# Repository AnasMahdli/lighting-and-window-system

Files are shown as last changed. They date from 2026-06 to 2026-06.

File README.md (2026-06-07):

# Setup Guide

---

## ⚙️ Hardware Setup

Connect a **12V 2A adapter** to power the complete system.

- The motor drivers (**L298N**) are connected directly to the **12V supply** to prevent brownouts during heavy loads.
- Use a **buck converter** to step down the voltage to **5V** to safely power the ESP32 and the sensor suite (DHT22, LDRs, PIR, MQ5).

---

## 💻 Software Setup

### Required Libraries

Install the following libraries in your **Arduino IDE**:

| Library | Author |
|---|---|
| `ArduinoJson` | Benoit Blanchon |
| `WebSockets` | Markus Sattler |
| `DHT sensor library` | Adafruit |
| `UbidotsEsp32Mqtt` | Ubidots |

### Cloud Configuration

1. Add your Wi-Fi **`SSID`** and **`Password`** to the ESP32 code.
2. Replace the GCP WebApp URL with your specific **Google Apps Script deployment URL**.
   > **Note:** If you update your Apps Script code, you must publish a **"New Deployment"** for the changes to take effect.
3. Ensure your **BigQuery Studio** table schema exactly matches the variable names in your payload (e.g., set `gas_level` to `FLOAT`).

---

## ☁️ Ubidots Setup (MQTT)

To utilize the cloud dashboard:

1. Copy your **Ubidots Token** and **Device Name** into the ESP32 code.
2. In your Ubidots Dashboard, create a new device and add the following raw variables:
   - `system-mode`
   - `fan-control`
   - `curtain-control`
   - `window-control`
3. Link these variables to **toggle switches** on your dashboard. These will publish commands to the ESP32 via the MQTT `/lv` (Last Value) topics.

---

## 🌐 WebSocket Setup (3D Digital Twin)

To run the local First-Person 3D Control Room:

### Prerequisites

1. Download and install the latest **LTS version of Node.js** from [nodejs.org](https://nodejs.org).
2. Download **Ngrok**, extract it, and authenticate your token via the command terminal.

### Installation

Open a command prompt in your project folder and install the required dependencies:

```bash
npm install ws
```

### Running the Servers

You will need **three separate terminals** open in your project folder.

**Terminal 1 — Start the WebSocket Broker:**

```bash
node server.js
```

**Terminal 2 — Host the 3D Files:**

> Note the port used — typically `8081` if `8080` is already taken by the broker.

```bash
npx http-server -p 8081
```

**Terminal 3 — Expose the WebSocket Broker via Ngrok:**

```bash
ngrok http 8080
```

### Connecting the Digital Twin

1. Ngrok will generate a **forwarding URL** in Terminal 3.
2. In your `3d-dashboard.html` file, update the WebSocket connection using the `wss://` prefix:
   ```
   wss://new-random-words.ngrok-free.dev
   ```
3. In your **ESP32 code**, paste the exact same URL but **remove the prefix**:
   ```
   new-random-words.ngrok-free.dev
   ```
4. Open your browser and navigate to:
   ```
   http://127.0.0.1:8081/3d-dashboard.html
   ```

The 3D environment should now render and sync with your physical hardware in real-time. 🚀

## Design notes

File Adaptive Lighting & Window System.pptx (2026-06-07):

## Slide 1

Adaptive Lighting &
Window System

Autonomous IoT Environmental Control & 3D Digital Twin Integration

Anas Hatem Mahdali | 239045

The British University in Egypt | Industrial Internet of Things | 25MTRN04H

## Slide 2

The Cost of Energy Waste

12.05

kWh Wasted Per Home/Year

Inefficient Resource Management

Average households lose significant energy due to forgotten lighting and ventilation. This project leverages the ESP32 to bridge the gap between occupant behavior and environmental efficiency.

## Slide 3

System Objectives

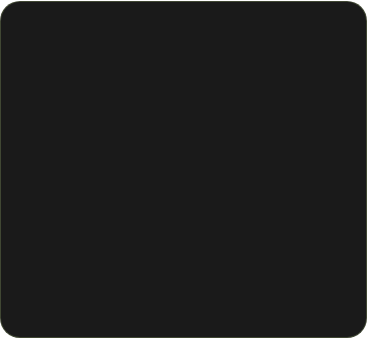
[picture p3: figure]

Autonomy

Intelligent control of lighting and windows based on real-time sensory perception.

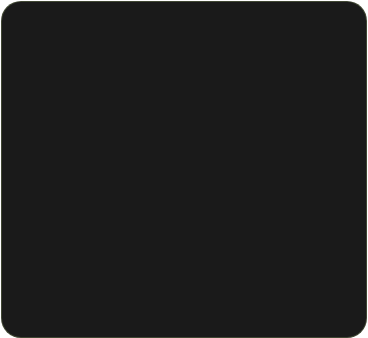
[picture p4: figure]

Safety

Prioritizing human life through advanced gas leak detection and automated ventilation.

Transparency

Real-time telemetry mirrored through 2D cloud dashboards and 3D digital twins.

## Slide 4

Perception Layer: Sensors

DHT22: High-precision temperature and humidity tracking.

LDR 1 & 2: Mapping interior vs. exterior ambient light intensity.

PIR Sensor: Passive Infrared detection for motion-based lighting.

MQ5 Sensor: Critical detection for combustible gases (LPG/Methane).

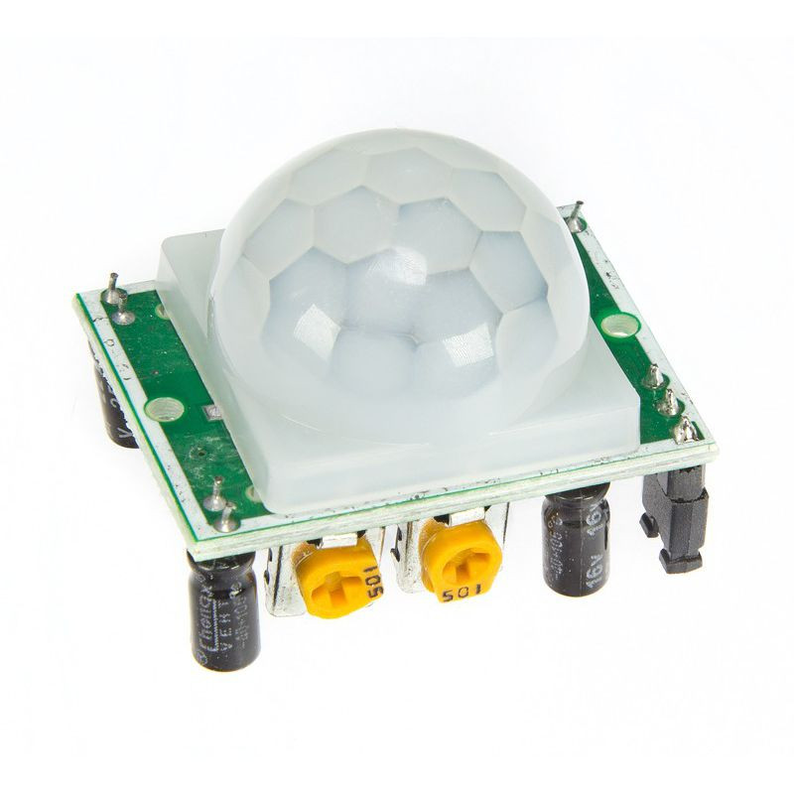
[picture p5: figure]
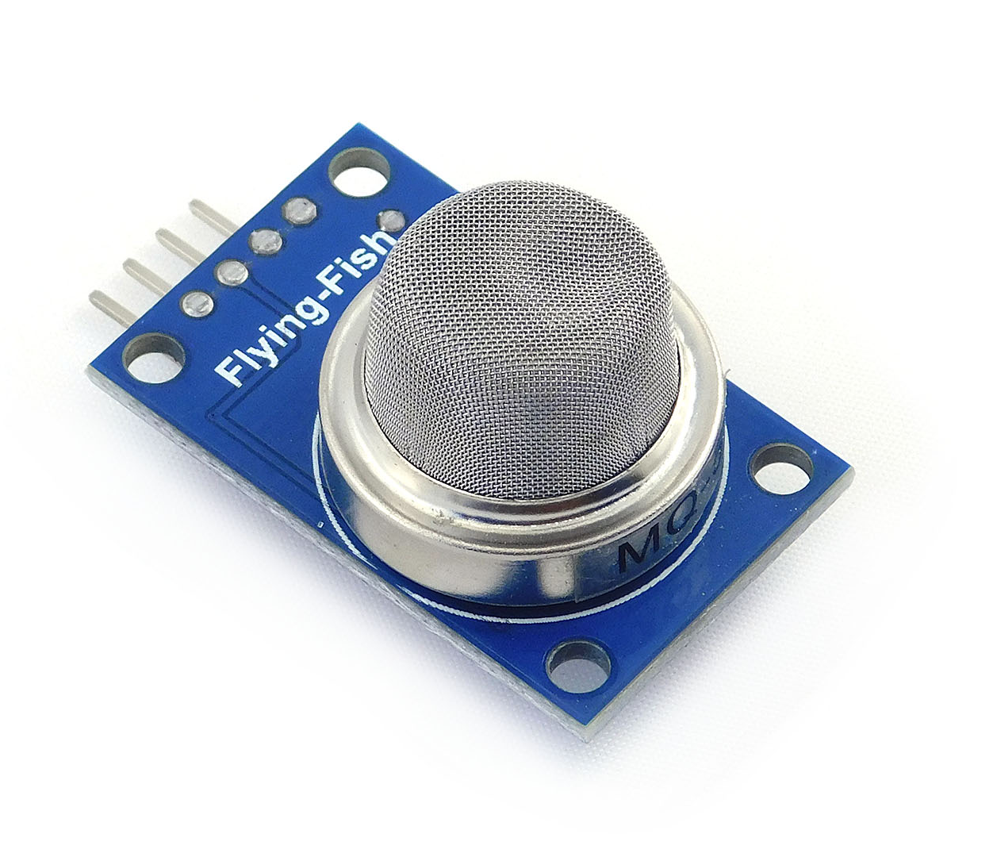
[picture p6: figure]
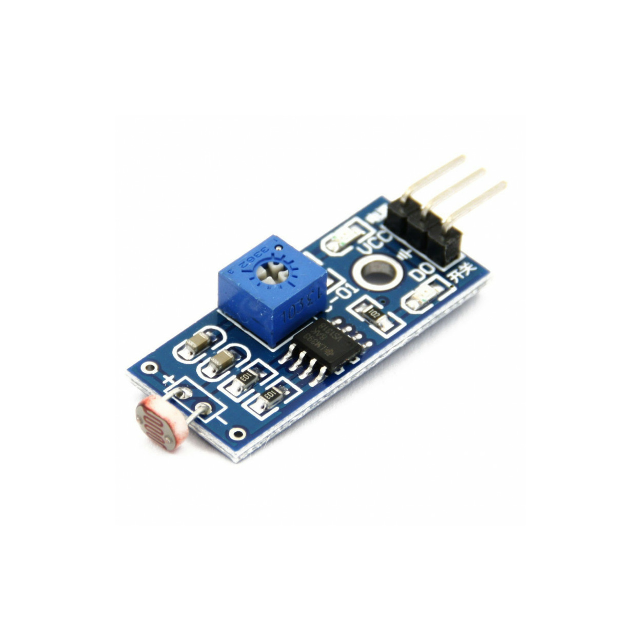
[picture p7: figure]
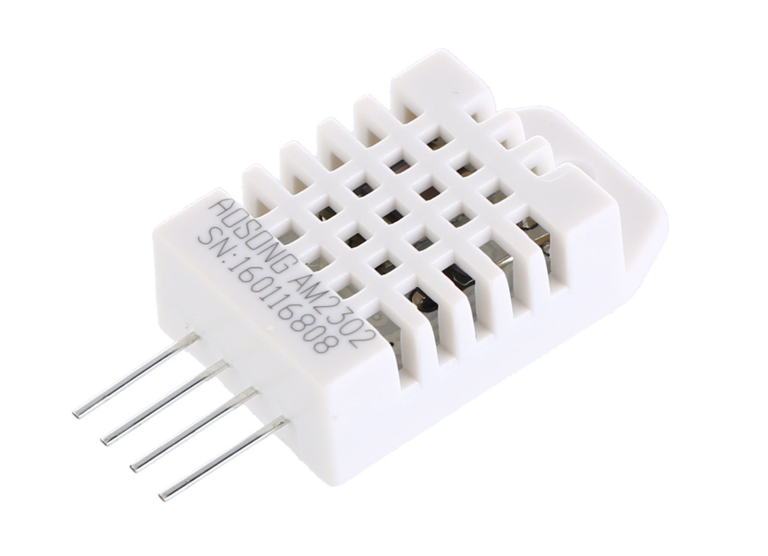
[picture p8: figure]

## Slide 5

Action Layer: Actuators

Motion Controls

Window and curtain sliding mechanisms driven by L298N drivers with precisely timed pulses.

Active Ventilation

L9110 Fan Module used for rapid room cooling and toxic gas expulsion.

Smart Lighting

High-efficiency 3W LED Module providing 200 lumens of occupancy-based illumination.

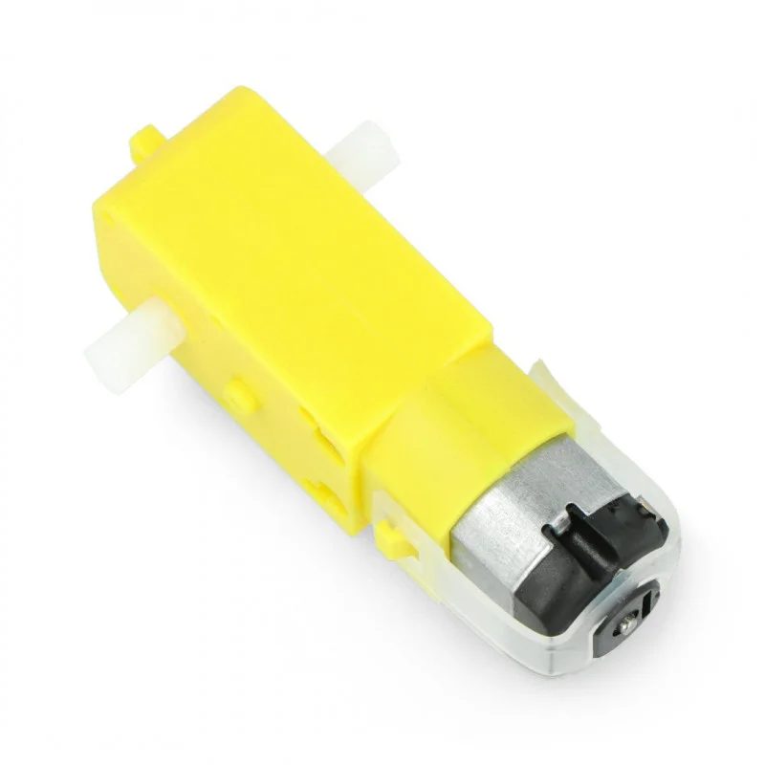
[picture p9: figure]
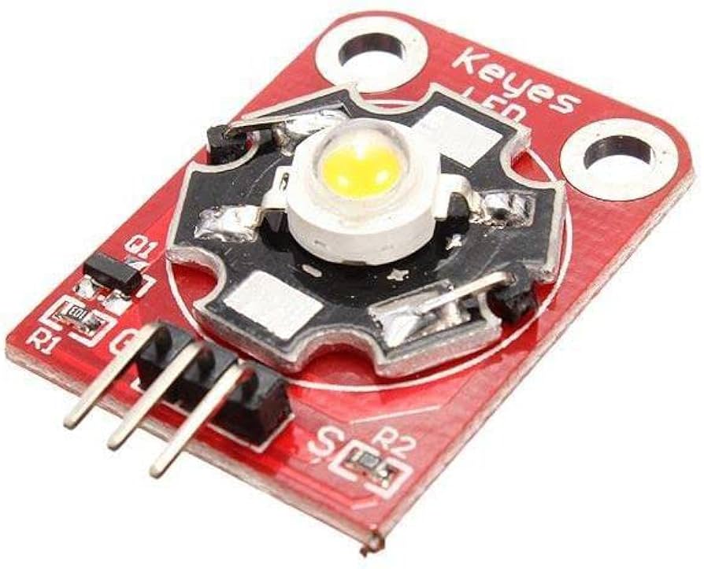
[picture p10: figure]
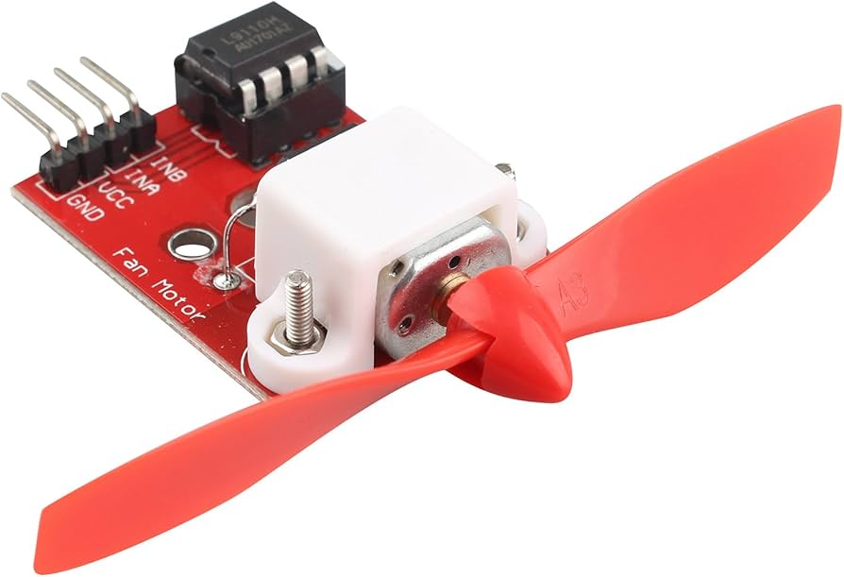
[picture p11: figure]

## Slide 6

State Management Hierarchy

Tier 1: Absolute Failsafe: High-priority emergency protocol that overrides all local and remote inputs during gas detection.

Tier 2: Automated Mode: Intelligent regulation using thermal thresholds (>30°C) and light intensity (>2000 lux).

Tier 3: Manual Override: Direct cloud-based control via MQTT topics, granting user agency over specific actuators.

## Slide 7

Emergency Protocol

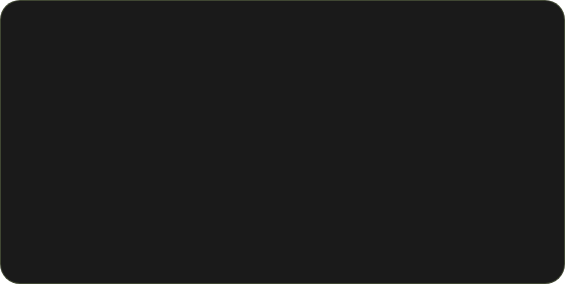
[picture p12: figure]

Trigger: 60% Gas

Upon detecting combustible gas levels exceeding 60%, the system initiates a total lockout, forcing windows and curtains open while engaging full-power ventilation.

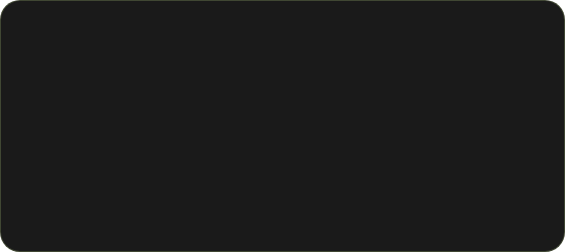
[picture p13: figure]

Release: 40% Gas

To prevent motor stuttering from sensor jitter, the "Hysteresis" logic only releases control once levels drop safely below 40%.

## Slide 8

Network Architecture

Multi-Pipeline Telemetry for Scalable IoT Performance

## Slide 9

Data Pipelines

Pipeline | Technology | Purpose | Update Rate
Real-Time Monitoring | Ubidots MQTT | 2D Dashboards & Remote Toggles | 5.0 Seconds
Historical Storage | GCP BigQuery | Long-term Data Analysis | 60 Seconds
Digital Twin | WebSockets (WS) | 3D Visualization & Low Latency | 2.0 Seconds

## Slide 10

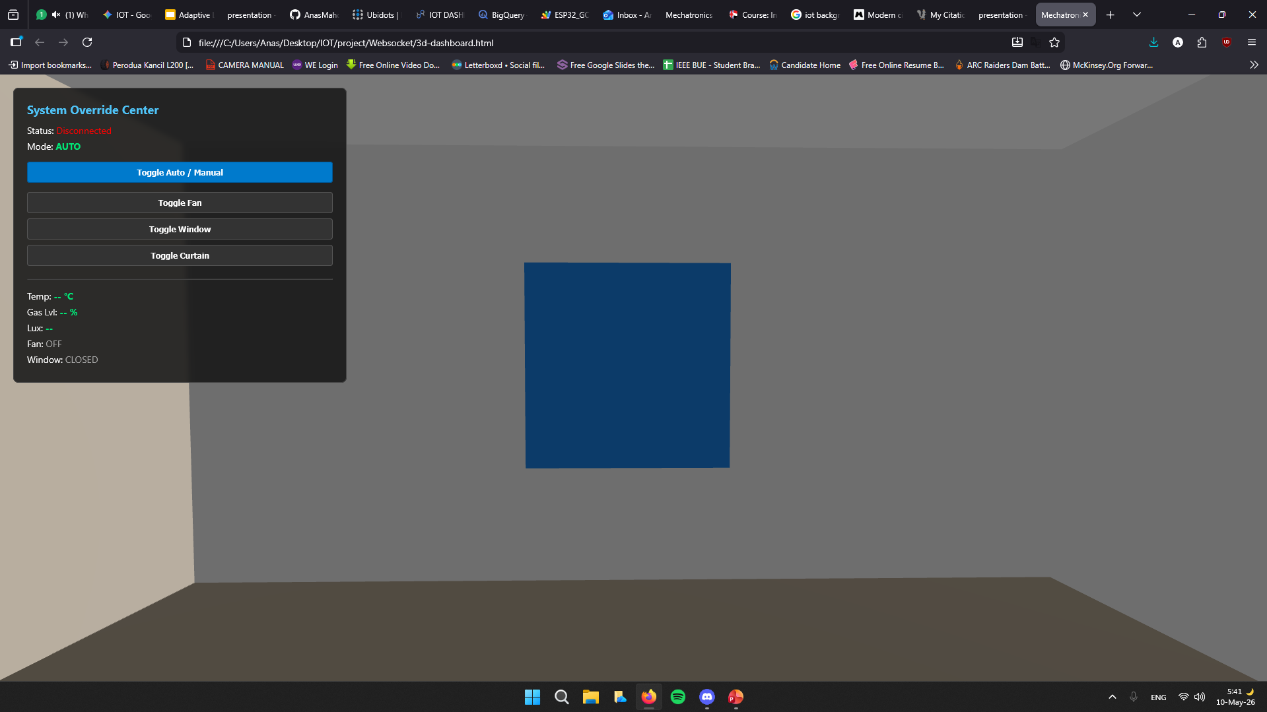
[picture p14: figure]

3D Digital Twin

Visual Mirroring

Built with Three.js and WebGL, the system features a 1:1 virtual replica of the physical environment. Actuators like fans and windows are animated in real-time to match physical motor timers.

Dynamic landscape textures swap based on LDR light data to simulate actual time-of-day environments.

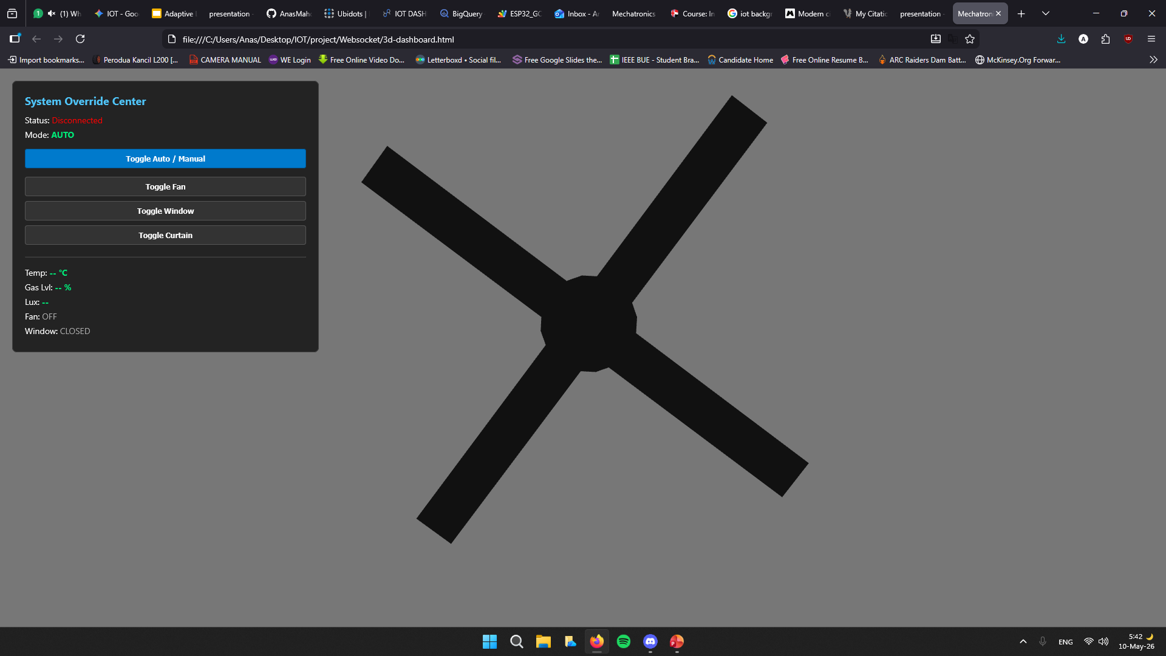
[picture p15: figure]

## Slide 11

Engineering Robustness

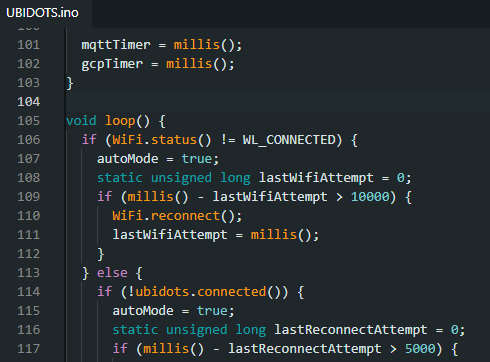
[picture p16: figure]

Offline Resilience

The system actively monitors Wi-Fi and MQTT links. If a connection failure is detected, the ESP32 automatically defaults to "Local Auto Mode," ensuring environmental stability without cloud commands.

Power Isolation

Logic (3.3V/5V) is strictly isolated from load (9V/12V). Independent power supplies for motor drivers prevent brownouts during simultaneous actuator engagement.

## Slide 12

Conclusion

Feasible low-cost microcontroller integration with high-fidelity 3D cloud telemetry.

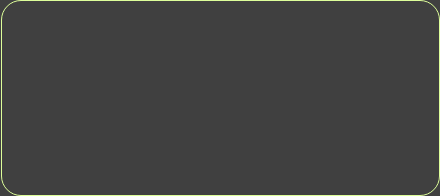
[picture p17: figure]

Any Questions?

anas239045@bue.edu.eg

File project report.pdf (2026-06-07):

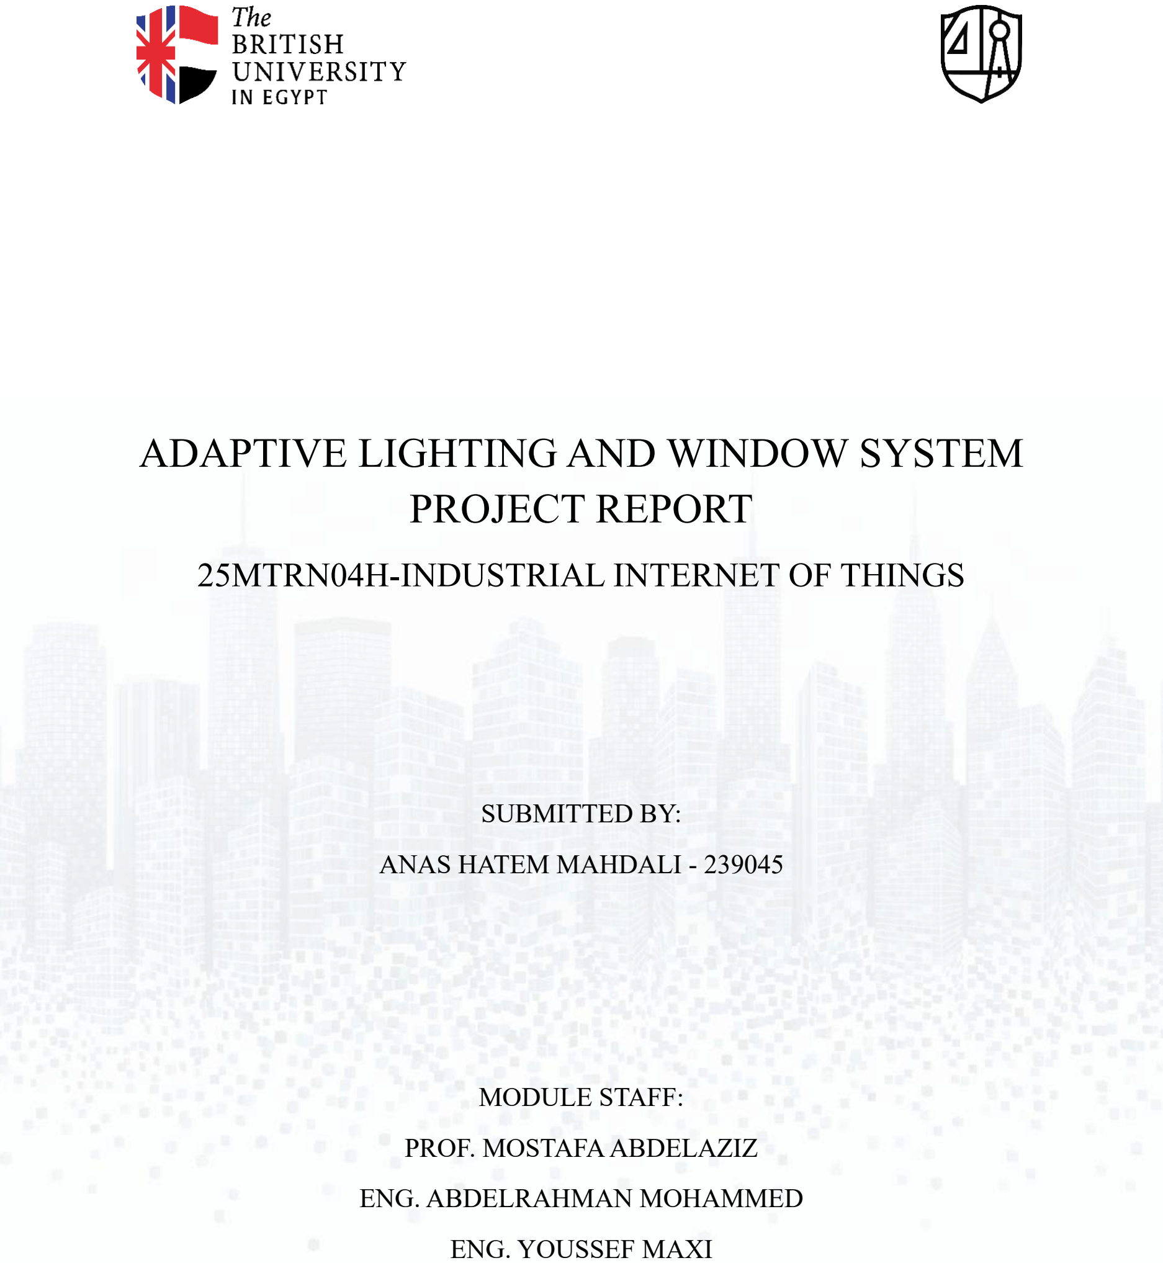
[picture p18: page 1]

# ADAPTIVE LIGHTING AND WINDOW SYSTEM PROJECT REPORT

## 25MTRN04H-INDUSTRIAL INTERNET OF THINGS

### SUBMITTED BY:

### ANAS HATEM MAHDALI - 239045

### MODULE STAFF:

### PROF. MOSTAFA ABDELAZIZ

### ENG. ABDELRAHMAN MOHAMMED

### ENG. YOUSSEF MAXI

## Table of Contents

## Introduction

Every day, almost every household has at least one occupant that will at some point forget the light on even if for a few minutes, another might even forget their fan on which is an even greater waste of energy. The article “How much light energy waste are UK households responsible for?” (100green(2023)) states that the average wasted kWh per household is 12.05kWh per year and that is just for the household lightbulb, this amount of energy can power a typical home for 12 house under essential loads.

This project describes the design and development of an IoT based centralized mechatronics system for autonomous lighting and window control. The system uses an ESP32 microcontroller to collect real-time data from the environment and to control physical components in order to ensure the best conditions in the room. A major element of this design is the ability to send and receive data in real time – giving operators access to up-to-the-minute information – as well as real-time remote manual override functions, with an inbuilt failsafe system for gas emergencies.

The system is mostly based on an MQTT protocol interface with the Ubidots cloud platform, which is used for telemetry and remote control. Moreover, the system is also configured with an additional HTTPS pipeline that sends the data to get logged to google bigquery and an additional feature is a local websockets architecture with more visualization capabilities than the ubidots dashboard

## Perception Layer

### Sensors

The system uses the ESP32 as the main processor and the following sensors are used to monitor the environment

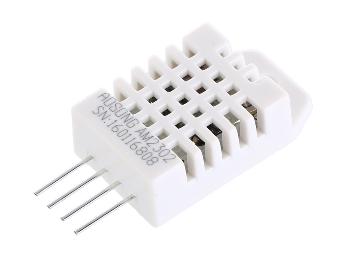
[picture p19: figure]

- DHT22 (Temperature & Humidity - Pin 32): Selected for its reliable digital output and accuracy compared to the LM35, it is also sold pre-calibrated which saves a lot of headaches

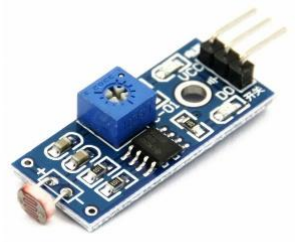
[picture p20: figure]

- LDR 1 & 2 (Photoresistors - Pins 34, 35): Analog light sensors which detect ambient light intensity. LDR1 monitors exterior light to identify the day/night cycle and automate the curtain mechanism. LDR2 monitors interior ambient light of the room.

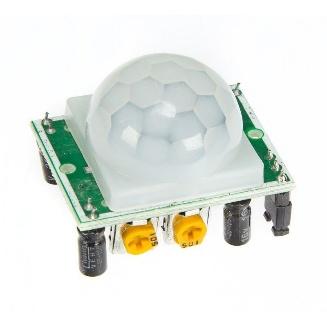
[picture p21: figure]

- PIR Sensor (Passive Infrared - Pin 25): Passive Infrared motion sensors detect movement by measuring changes in infrared radiation of nearby objects, it is used for localized automated lighting control.

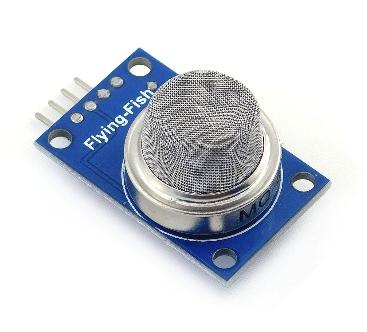
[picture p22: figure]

- MQ5 Gas Sensor (Combustible Gas - Pin 33): Analog sensor used to detect even trace amounts of LPG, natural gas, methane and propane. Critical for the system's emergency failsafe protocol.

### Actuators

- Window Motor Mechanism (Pins 26, 27): Driven by an L298N Motor Driver. Operates on a timed continuous rotation found through calibration with distances and available spaces

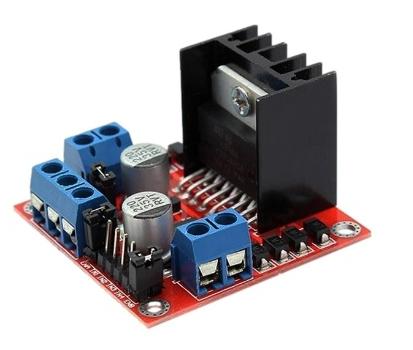
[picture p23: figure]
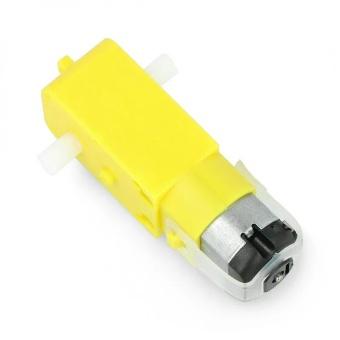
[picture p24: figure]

- Curtain Motor Mechanism (Pins 18, 19): Driven by an L298N Motor Driver. Operates on a 300ms hardware timer precisely calibrated for the available space and number of revolutions required

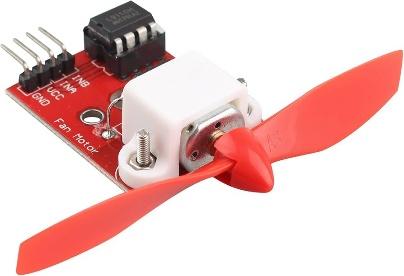
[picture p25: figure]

- L9110 Fan Module (Pins 22, 23): Directional DC fan for active ventilation in order to expel harmful gases and to lower room temperature to a comfortable degree

- 3W LED Module (Pin 2): Used as the primary lighting source for occupants of the room, emits from 180 to 200 lumens which is enough for the size of the room used

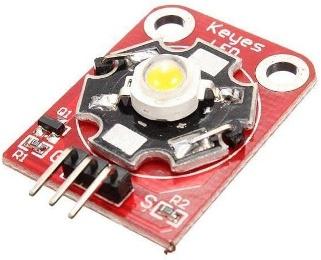
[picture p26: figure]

## Sensor Calibration & Signal Processing

Raw data from the sensors needs to be calibrated and conditioned so that it is available to the control logic and is easily digestible.

- MQ5 Gas Calibration: MQ5 needs to be powered for at least 2 minutes to stabilize the internal heating coil. In software, the analog reading is converted to a percentage (value / 4095.0) * 100 to get an analog reading from the 12-bit analog input
- Luminosity Mapping: The 12-bit LDR reading is inverted and mapped to an estimated Lux value to be used for human-readable display on the dashboard. The analog reading for daytime is set to <= 2000.
- Signal Noise Filtering: There is electrical noise from physical motors and analog sensors vary naturally. A hysteresis was added to the software logic to eliminate the fast switching, so that the emergency state is only activated at 60% PPM, and the emergency state will only be released on a drop to 40% PPM

## Control Systems & State Management

The firmware for the ESP32 has a multi-level structure in order to handle the system states and avoid logical conflicts between human inputs and sensor data.

### Tier 1: Absolute Failsafe Override (Emergency Protocol)

There's more to logic than just being safe. If the MQ5 detects gas concentrations exceeding 60%, the system enters an absolute lockout.

- Ignores all user inputs and automated temperature/light rules.
- It activates the cooling fan and automatic window to open for better air circulation
- To avoid motor stuttering due to sensor jitter, the system goes into emergency-mode and will not return control to the user until the gas concentration is safely below 40%

### Tier 2: Automated Control (Auto Mode)

The system works on its own under safe conditions:

- Thermal Regulation: If temperature is above 30.0°C, the window opens and the fan activates to ventilate the room

- Light Regulation: If outside light crosses the 2000 threshold that indicates daytime, the curtain automatically slides to open the window and power off the bulb to save energy

### Tier 3: Manual Override

Users can disable auto mode via the dashboard.

- The ESP subscribes to MQTT topics to receive target states for window, curtain and fan operation, overriding local operation
- The motor timers (windowMoving, curtainMoving) control when the logical state variable flips (e.g.: windowState = 1) to keep the hardware in sync
- The dashboard updates the 3D graphics as soon as a button is clicked and the ESP32 handles the physical actuation in the background.

## Network Architecture & Telemetry Pipeline

A ubidots dashboard was developed on this system, but to store the data in the cloud, the transmitted data was first passed through the google cloud platform and handled using HTTPS, and also to enable real-time control and bi-directional communication between the dashboard and the ESP32 a websocket was used, a simple dashboard was provided by ubidots as well.

The system utilizes a branched data pipeline to handle both real-time control and long-term data storage.

- Pipeline 1: Ubidots MQTT: the esp publishes telemetry every 5 seconds to the esp32-system device label, it also keeps listening to last value topics to receive state changes from the dashboard, the topics subscribed to from the esp are:
- /v2.0/devices/esp32-system/system-mode/lv
- /v2.0/devices/esp32-system/window-control/lv
- /v2.0/devices/esp32-system/curtain-control/lv
- /v2.0/devices/esp32-system/fan-control/lv

And the topics which the ESP publishes to are:

- /v2.0/devices/esp32-system/temperature
- /v2.0/devices/esp32-system/ldr-outside
- /v2.0/devices/esp32-system/gas-level
- /v2.0/devices/esp32-system/window-status
- /v2.0/devices/esp32-system/curtain-status
- /v2.0/devices/esp32-system/fan-status
- Pipeline 2: Long-Term Cloud Storage: The ESP32 makes a secure HTTPS get request to a Google Apps Script Web App every 60 seconds. Parses URL parameters (temp, lux, gas, led status) and commits a dataset containing the data and the timestamp into a Google Cloud BigQuery dataset to be used for future data analysis..

- Pipeline 3: Low-Latency WebSockets: To be used as alternative dashboard, the ESP32 is connected to the local Node.js WebSocket Broker that is used on the pipeline 3 named Low-Latency WebSockets. This broker has a secure ngrok tunnel exposed to the internet. This was achieved by using a 3D Digital Twin that was driven by a serialized JSON payload sent from the ESP32 every 2 seconds, avoiding blocks imposed by browser CORS restrictions (Cross-Origin Resource Sharing), a security feature of the browser which prevents scripts from one origin from making requests to another via a local http server

## The 3D Digital Twin (UI)

The user interface abandons traditional 2D dashboards and introduces a WebGL and Three.js based First-Person 3D Virtual Control Room

- Real-Time Mirroring: The 3D scene is rendered to produce the state of physical hardware dynamically. Virtual fan rotates constantly when physical fan operates, virtual window and virtual curtains move along Z and X axes to synchronize with the physical motor timers
- Dynamic Environments: The Three.js scene dynamically changes to high resolution texture maps (Day/Night landscapes) outside the virtual window using the sensor data collected by the LDR sensor, which simulates real lighting.
- CORS Bypass: To load local high-resolution textures without triggering browser Cross-Origin Resource Sharing (CORS) security blocks, the HTML file is served via a local Node http-server. To avoid browser Cross-Origin Resource Sharing (CORS) security blocks for loading high-resolution local textures, the HTML file is being served from a local Node http-server

## Critical Power Management Considerations

The MQ5 sensor has considerable power consumption as a result of its internal heating element (~150mA continuous). The ESP32 turns on the MQ5 heater, two DC gear motors (window and curtains) and the ventilation fan simultaneously during a gas emergency.

The logic level (ESP32) needs to be separated from the load level (L298N motor drivers) because if the voltage drops to a catastrophic level, the ESP32 will reset, and the motor drivers will enter an infinite loop. There is an independent 9V/12V high-current power supply with common ground connected to the microcontroller, providing power to the motor drivers

## Robustness


It is resilient in the sense that in the event of connection failure, the system continues to offer the same automatic functionality, avoiding system failure.

The system actively watches the Wi-Fi link and the MQTT connection: if either one is down, the esp will reset the automode to the true state, so the system will not get in a loop waiting for cloud commands that will no longer be received

## Conclusion

The system is able to show the feasibility of low cost microcontroller integration with sophisticated cloud based telemetry and 3D visualization. The system's energy-saving capabilities are achieved through a tiered control architecture and the use of the ESP32, overcoming the problems of energy waste identified in the introduction and making the living area responsive and energy-efficient.

All primary design objectives are addressed: autonomy, safety and manual transparency. The local environmental regulation is maintained even if the network is unstable, with the so called "Offline Resilience" function of the system. This prototype is a scalable model for energy management in today's smart home, demonstrating that smart energy management can be realized without sacrificing user safety or the lack of operational oversight.

## References

How much light energy waste are UK households responsible for?. 100Green. (2023, September 14). https://100green.com/blog/news/uk-light-energy-waste/

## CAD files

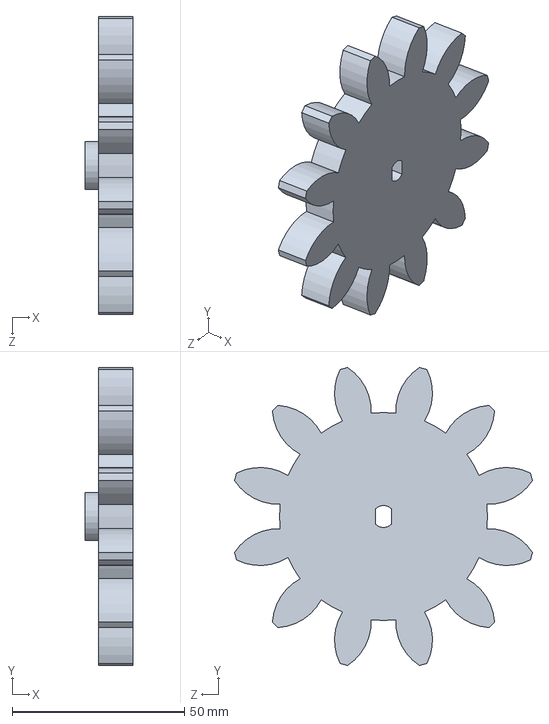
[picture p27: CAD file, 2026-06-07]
3D printed parts/gear.SLDPRT
14.0 x 86.4 x 86.4 mm

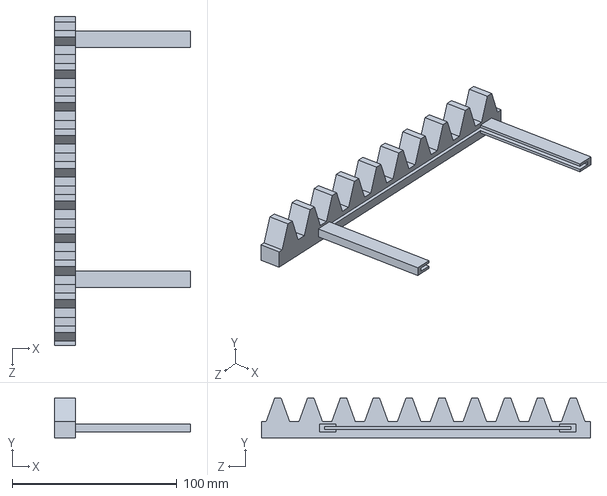
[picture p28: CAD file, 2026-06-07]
3D printed parts/rack.SLDPRT
82.7 x 24.1 x 200.0 mm

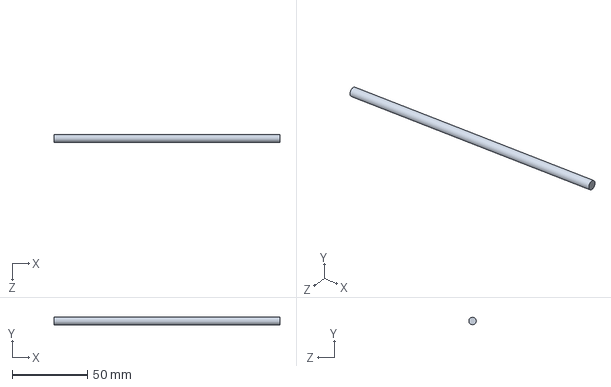
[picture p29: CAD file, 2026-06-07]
3D printed parts/support.SLDPRT
150.0 x 4.99 x 5.00 mm

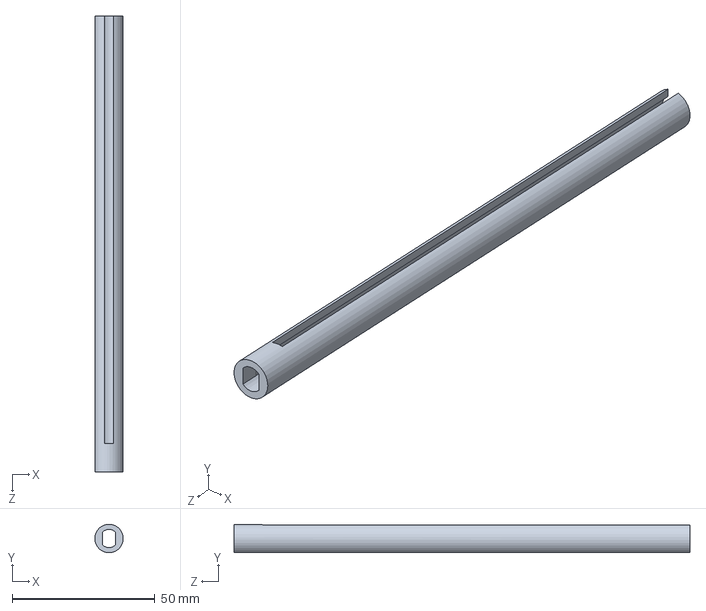
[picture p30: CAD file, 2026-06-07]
3D printed parts/curtain_rod.SLDPRT
10.0 x 9.99 x 160.0 mm

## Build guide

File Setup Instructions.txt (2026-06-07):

Hardware Setup:---------------------------------------------------

Connect a 12V 2A adapter to power complete system, motors are connected directly to the adapter,
and use a buck converter to step down the voltage to 5V to power everything else

Software Setup:---------------------------------------------------

Install Arduino Libraries (ArduinoJson by benoit Blanchon), (Websockets by Markus Sattler), (DHT sensor library by Adafruit)

Add the network SSID and Password to the code so the ESP can connect to the internet and replace 
the GCP WebApp URL with yours to connect to the google cloud platform and do not forget to add the variables
in BigQuery Studio 

Ubidots Setup:-----------------------------------------------------

To use the Ubidots dashboard, simply copy your Ubidots credentials(Default token and device name) to the code 
and add system-mode, fan-control, curtain-control, window-control topics as raw variables to send to the ESP

Websocket Setup:-------------------------------------------------

To use the 3D dashboard, first download latest LTS node.js from nodejs.org

download ngrok, extract and run auth token(found in ngrok dashboard) in command terminal
 
open the command prompt in the project folder and run (npm install), if it does not work then run (npm install ws)

open a new terminal(1) in project folder and run (node server.js)

open a new terminal(2) in project folder and run (npx http-server)

open the ngrok terminal(3) and run (ngrok http 8080)

now in the ngrok terminal you should find a websocket url similar to this (wss://new-random-words.ngrok-free.dev), 
copy this link and paste it in the 3d-dashboard.html file and the esp32 code too but remove the "wss://" prefix so put only the 
"new-random-words.ngrok-free.dev" part of the URL

then in your browser open http://127.0.0.1:8080/3d-dashboard.html and the dashboard should be visible and update in realtime

----------------------------GoodLuck:)----------------------------
